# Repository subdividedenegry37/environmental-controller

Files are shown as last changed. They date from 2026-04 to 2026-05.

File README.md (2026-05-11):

# Environmental Controller

Dual-relay humidity and vapor pressure deficit (VPD) controller built around a custom ESP32/RP2040 PCB.
End-to-end project: firmware, schematic, 2-layer PCB layout, and 3D-printed enclosure, all designed and built from scratch.

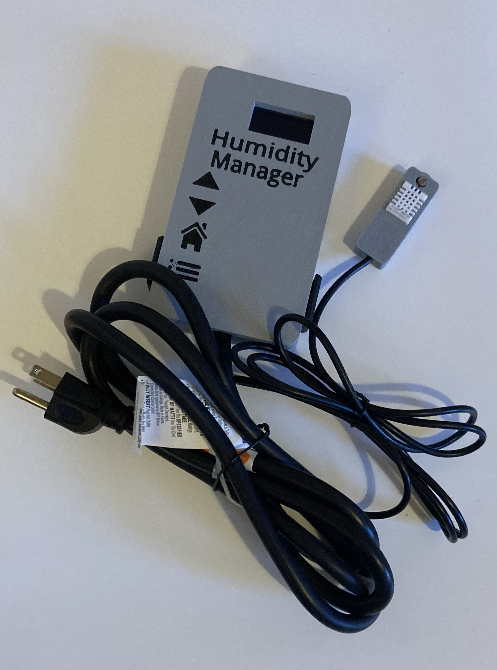
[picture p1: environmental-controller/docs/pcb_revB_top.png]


---

## What it does

Enviirmental controller that targets VPD rather than relitive humidity. Monitors temperature, humidity amd computes VPD. Controller switches between AC relays driving a humidifier or a dehumidifier to hold a target VPD during the day. Additional Day/night setting controlled by ambient light sensor. Four pushbuttons and a 128×64 OLED display provide a UI for setting targets, sensor offsets, and display preferences. All user settings are persisted to flash and restored on power-up.

Applications for a VPD/humidity controller of this class include greenhouse and horticulture environments, cleanroom and storage humidity control, museum and archive climate control, and any enclosed space where temperature-compensated humidity targeting is preferable to raw RH control.

---

## Hardware

**Microcontroller:** RP2040 soldered directly to the board with minimal design. Onboard USB-to-serial IC handles programming and debug. BOOT and RESET buttons are broken out to the board edge.

**Sensors:**
- DHT22 (AM2302) digital temperature and humidity sensor
- Analog photoresistor for ambient light / day–night detection

**Output stage:**
- Two 5V mechanical relays switching 120 VAC mains loads
- Flyback diodes on each relay coil for back-EMF protection
- Slot cutout between the low-voltage logic section and the AC main section for creepage clearance isolation

**User interface:**
- SSH1106 128×64 I2C OLED display
- Four momentary pushbuttons (up, down, back, next/settings)

**Power and I/O:**
- 120 VAC mains input via screw terminals (L, N)
- Two switched 120 VAC output terminals (O1, O2) for humidifier and dehumidifier loads
- 3.3 V logic rail for ESP32 and sensors
- Sensor pin header breakout for DHT22, light sensor, GND, and 3V3

---

## Firmware

Initial Arduino-framework C++ (`RewriteV4_5.ino`), targeting the ESP32 via the Arduino core. Key design decisions:

**Non-blocking main loop.** No `delay()` calls in the main execution path. Each subsystem — sensor reads, display refresh, EEPROM save check, light sensor averaging — runs on its own cadence using `millis()` deltas. This keeps the UI responsive and the control loop prompt regardless of what any one subsystem is doing.

**Hysteretic relay control with dead time compensation.** The DHT22 responds in seconds, but room air takes minutes to actually equilibrate after a humidifier or dehumidifier kicks on. Without a tolerance band around the setpoint, the fast sensor response versus slow physical response produces continuous oscillation and cycles the relays constantly. The control logic tracks which device was most recently active and uses a tolerance band to define a dead zone around the target — the relay does not re-engage until the measurement crosses the opposite side of the band. This both prevents oscillation and extends mechanical relay life.

**Sensor smoothing via moving averages.** DHT22 outputs are noisy by nature; the analog photoresistor is noisier still. Each sensor feeds a 10-sample ring buffer, and control decisions are made against the average rather than the instantaneous reading.

**EEPROM wear protection.** The save routine fires on a 30-second timer but only performs EEPROM writes if any stored value has actually changed since the last save. This bounds EEPROM cycling to actual user interaction and prevents flash wear from the periodic poll.

**Independent day and night control modes.** Day mode targets VPD (a combined function of temperature and humidity); night mode targets relative humidity directly. Mode switches automatically from the light sensor reading with a configurable cutoff threshold.

**State-machine UI.** A `SettingsScreenState` byte drives a six-screen menu (VPD target, humidity offset, temperature offset, leaf offset, night mode enable, night humidity target). Button mapping is context-sensitive to the active screen.

---

## PCB

Full 2-layer PCB designed in EasyEDA. Complete Gerber sets for both revisions are included in `pcb/`, ready to send to any fab house.

**Revision A — initial working board:**

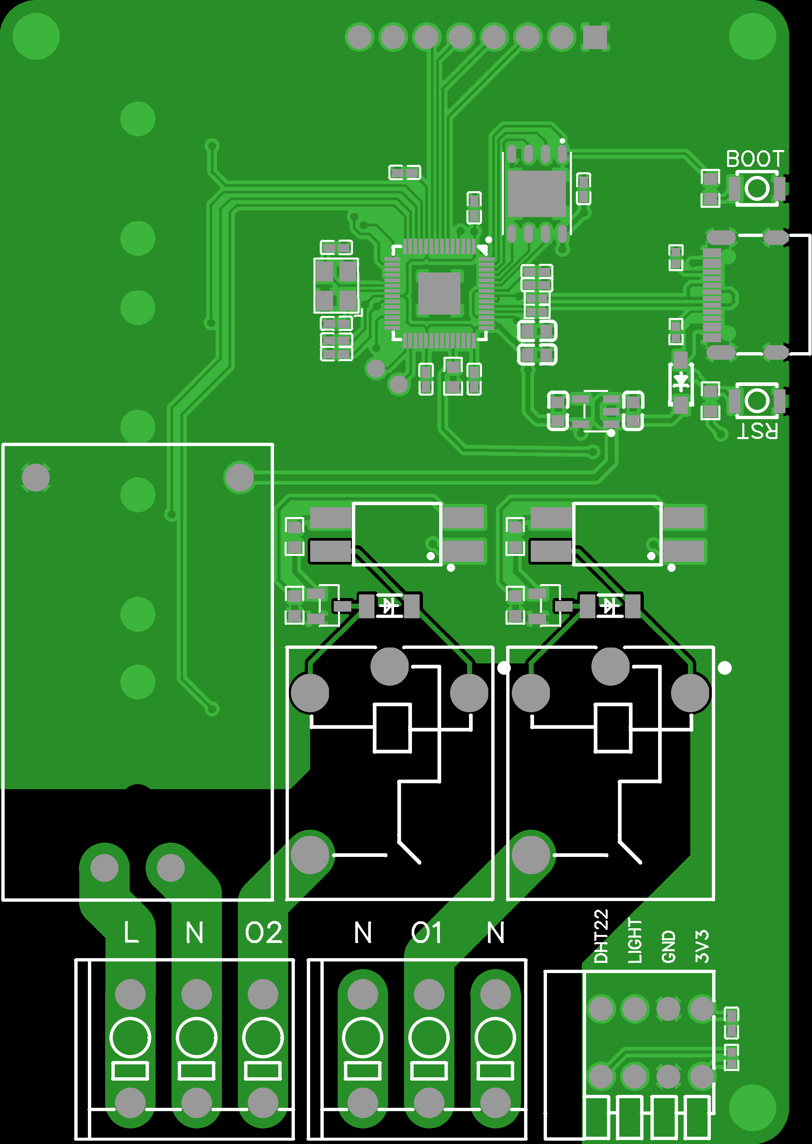
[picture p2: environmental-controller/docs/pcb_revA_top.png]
PCB revision A, top view


3rd ideration of board, self driven, added spring clamp, button header, and display header to aid in assembly. Added additional saftey features as well to manage AC/DC seperation.

**Revision B — refined layout:**

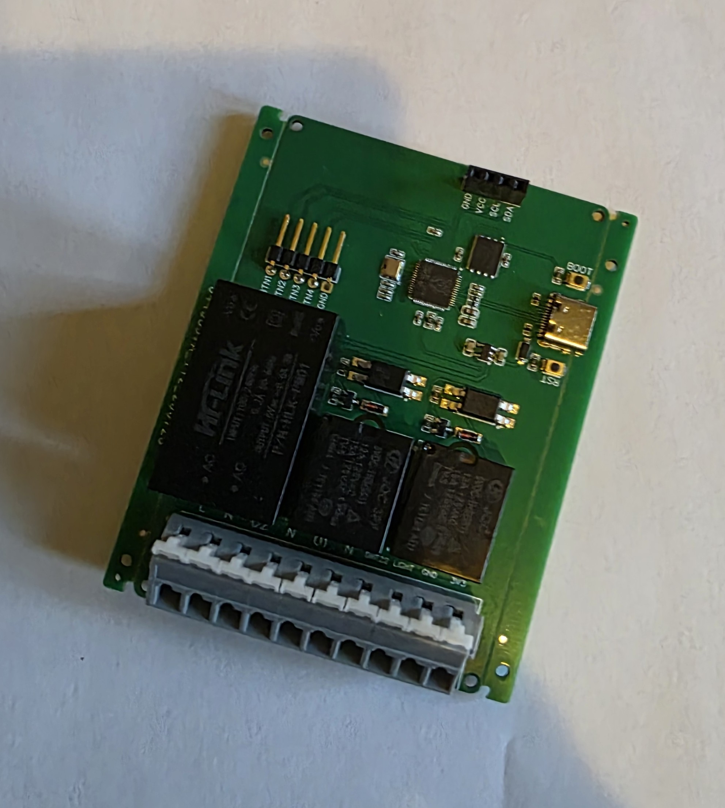
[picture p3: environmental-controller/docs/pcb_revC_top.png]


Unified terminal strip along the bottom edge for all power and sensor connections, dedicated labeled headers for the four front-panel buttons (BTN1–BTN4), and an explicit I2C header at the top (GND/VCC/SCL/SDA) for the OLED. 

Both revisions keep a slot cutout between the mains and logic sections for creepage clearance — standard safety practice for any PCB that switches AC line voltage from the same board as its low-voltage logic.

**Design history.** Initial PCB layout was attempted through two contracted specialists via freelancing platforms; neither delivered a working board. Rather than continue contracting, the layout was self-taught and done in-house — which turned out to be both faster and better matched to the actual hardware constraints.

---

## Enclosure

3D-printable enclosure designed in Fusion 360, printed on a Bambu Lab multi-color FDM printer to allow the button labels to be printed directly into the top face of the lid rather than applied as stickers or silkscreen. Buttons themselves are nexted into the print as well.

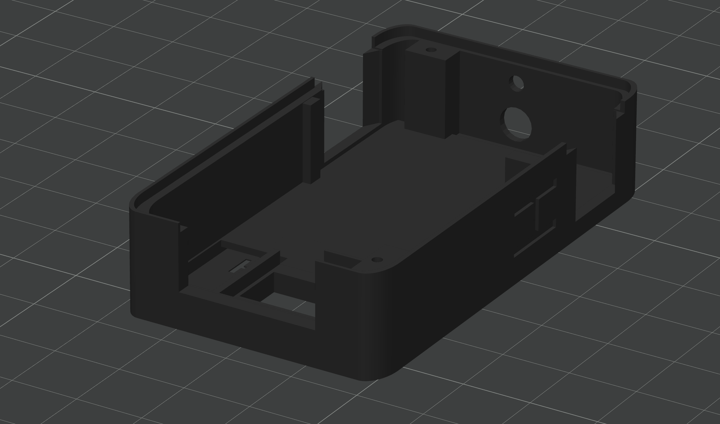
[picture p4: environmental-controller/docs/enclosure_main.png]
Main enclosure


The main box includes a nested button pocket with a thin top layer which gives a cleaner finished look and better tactile feel. Labels are printed directly into the box.

The DHT22 and photoresistor are housed in a small separate enclosure connected to the main unit via a short cable, so the sensor can be positioned at the measurement location independently of the controller.

Both AC outlets clip into place and screen sits directly in the board breakout making for simple assemply.

STL files in `enclosure/`.

---

## Repository layout

```
environmental-controller/
├── firmware/
│   └── RewriteV4_5.ino          Arduino-framework ESP32 firmware
├── pcb/
│   ├── rev_a/                   Gerbers, drill files for first board revision
│   └── rev_b/                   Gerbers, drill files for refined revision
├── enclosure/
│   ├── Box.stl                  Main enclosure body
│   ├── newTopcurveaa.stl        Top cover with button pockets
│   ├── Sensort.stl              Remote sensor housing
│   └── box6.stl                 Alt enclosure revision
├── docs/
│   └── (rendered images used in this README)
└── README.md
```

---

## Status and honest notes

This was an early self-taught embedded-systems project (2019–2022). It was my first serious firmware, first custom PCB, and first real enclosure design. The firmware is kept in its original form rather than refactored to modern practice: there are a lot of global variables, three separate copies of the moving-average logic (one for VPD, one for humidity, one for light), and variable naming is not consistent across the file. The underlying architecture — non-blocking scheduling, hysteretic control with dead-zone compensation, EEPROM wear protection, sensor smoothing, a proper menu state machine — is sound. The surface-level code style reflects someone learning C++ while building the thing.

If I were rebuilding this today, I'd encapsulate the per-sensor state into structs, collapse the three ring-buffer implementations into one reusable class, and move constants and pin assignments into a separate header. None of those changes would alter what the device does; they'd just make the project easier to maintain. For the purposes of keeping an honest record of what I built while teaching myself, the original file stays.

---

## License

MIT

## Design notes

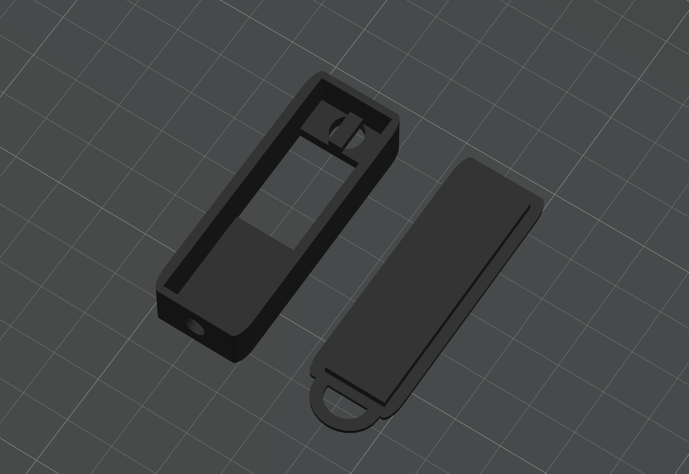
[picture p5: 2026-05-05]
environmental-controller/docs/sensor_housing.png

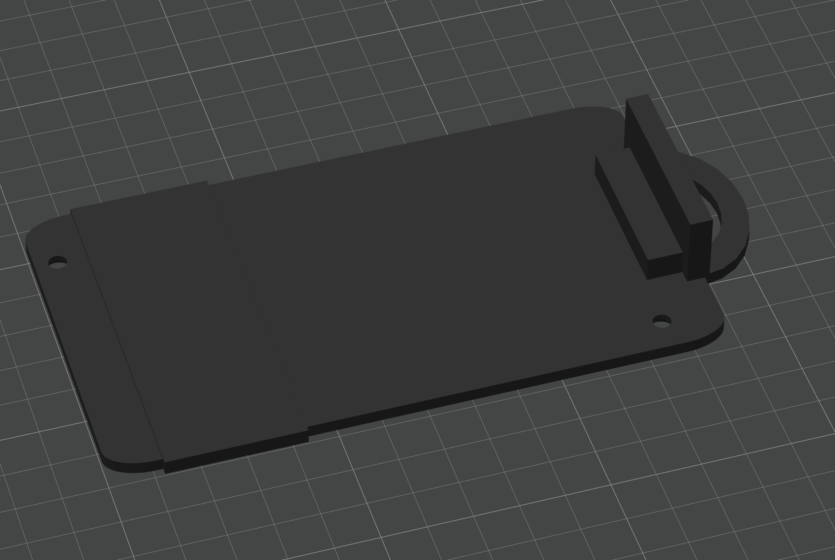
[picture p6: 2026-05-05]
environmental-controller/docs/enclosure_top_cover.png

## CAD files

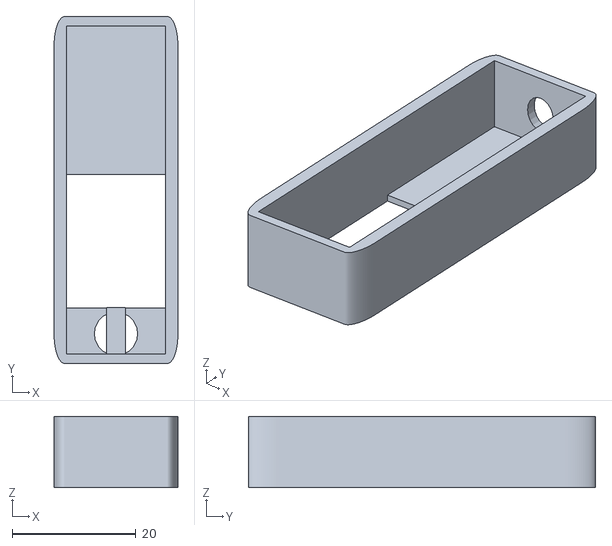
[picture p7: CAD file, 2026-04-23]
environmental-controller/enclosure/box6.stl
20.0 x 56.0 x 11.5

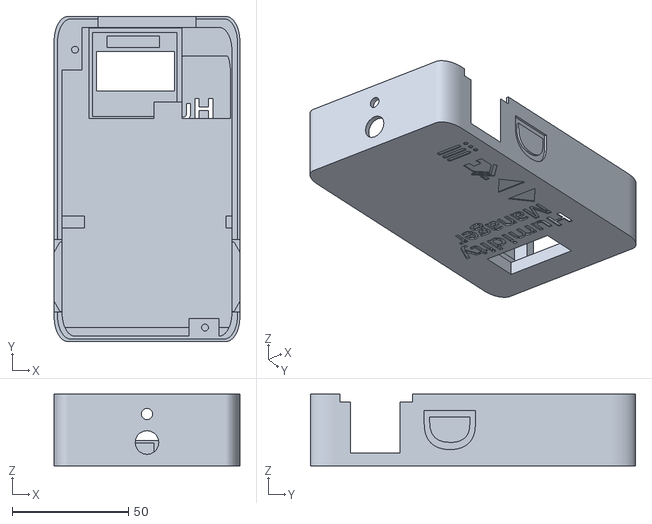
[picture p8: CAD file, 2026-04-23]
environmental-controller/enclosure/Box.stl
80.0 x 140.0 x 31.0

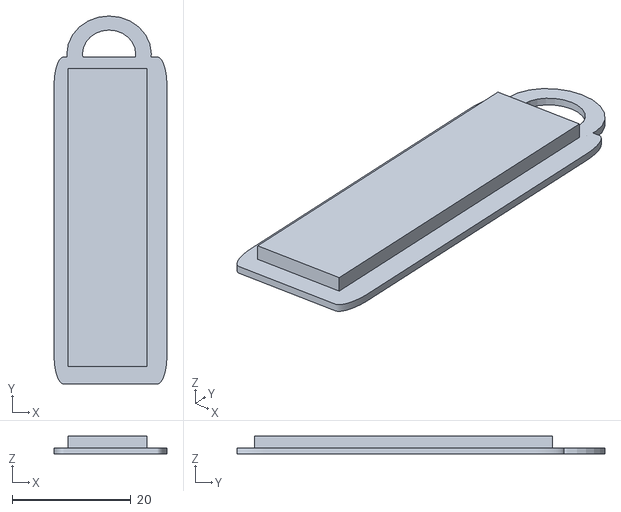
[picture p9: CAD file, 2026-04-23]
environmental-controller/enclosure/Sensort.stl
19.0 x 62.0 x 3.00

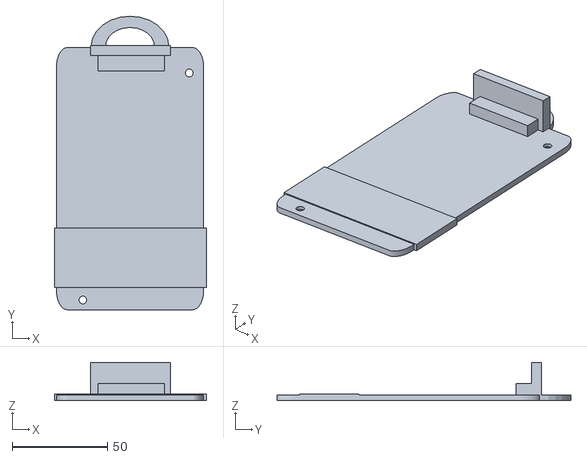
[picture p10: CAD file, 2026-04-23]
environmental-controller/enclosure/newTopcurveaa.stl
80.0 x 154.5 x 20.0

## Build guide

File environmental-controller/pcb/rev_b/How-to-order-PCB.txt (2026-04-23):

How to Order PCB

Please refer to:
https://docs.easyeda.com/en/PCB/Order-PCB

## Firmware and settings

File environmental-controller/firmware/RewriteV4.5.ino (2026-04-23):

/*
 * Environmental Controller
 *
 * Dual-relay humidity / vapor pressure deficit (VPD) controller for an
 * enclosed environment. Reads temperature and relative humidity from a
 * DHT22, reads ambient light from an analog photoresistor, and drives
 * two AC relays (humidifier and dehumidifier) through a hysteretic
 * control loop with independent day and night modes.
 *
 * Hardware:
 *   - Arduino Uno / Nano (ATmega328P)
 *   - DHT22 temperature and humidity sensor
 *   - SSH1106 128x64 I2C OLED display
 *   - Analog photoresistor / LDR for day-night detection
 *   - Two mechanical relays driving 120VAC loads
 *   - Four momentary pushbuttons for menu control
 *   - Settings persisted to on-board EEPROM
 *
 * Control strategy:
 *   - 10-sample moving averages on temperature, humidity, and light
 *     readings to reject DHT22 noise and smooth analog variation
 *   - Hysteresis bands around target values to accommodate the dead
 *     time between relay switching and room-air equilibration. Without
 *     this, fast sensor response versus slow physical response produces
 *     continuous oscillation around the setpoint.
 *   - Day mode targets VPD (function of temperature and humidity);
 *     night mode targets relative humidity directly
 *   - EEPROM writes gated on change detection to prevent flash wear
 *   - Non-blocking main loop: sensors, display, EEPROM, and light
 *     sensor each run on independent timers using millis() deltas
 *
 * Status:
 *   Early self-taught embedded project (2020-2022). Kept in its
 *   original working form; heavy use of globals and repeated
 *   moving-average implementations reflect that origin.
 */

#include <Wire.h>
#include <EEPROM.h>
#include <DHT.h>

// Screen Set Up
#include <GyverOLED.h>
GyverOLED<SSH1106_128x64> oled;

// Sensor Set Up
#define DHTPIN 2
#define DHTTYPE DHT22
DHT dht(DHTPIN, DHTTYPE);

// Humidifier and Dehumidifier Settings
bool LastOnDehumidifier = false;
bool LastOnHumidifier = false;

// VPD
float StoredVPDMovingAverage[10] = {0, 0, 0, 0, 0, 0, 0, 0, 0, 0};
byte LastVPDArrayPos = 0;
float AveragedVPD = 0;
float CurrentVPD = 0;

// Humidity Sensor
float AveragedHumidity = 0;
byte LastHumArrayPos = 0;
float StoredHumidityMovingAverage[10] = {0, 0, 0, 0, 0, 0, 0, 0, 0, 0};

// Light Sensor
byte LastLightArrayPos = 0;
float LightTotalValues = 0;
int LightArraySize = 10;
float AvLight = 0;
float LightAnalog_Reading = 0; // light array readings are different, narrowning problem
float LightMovingAverage[10] = {0, 0, 0, 0, 0, 0, 0, 0, 0, 0};

// Settings Vars
float TargetVPD = 1;
const float VPDTolerance = .1;

float NightModeTargetHumidity = 60;
const float NightModeHumidityTolerance = 2;

int LeafOffset = 0;
int HumidityOffset = 0;
float TempOffset = 0;

bool DisplayF = true;
byte SettingsScreenState = 0;
bool SleepMode = false;
bool NightMode = false;
bool NightModeEnabled = false;
byte RelaySetting = 0;

int LightSensorCutoff = 950;


// Relay Pins
const byte HumidifierPin = 10;
const byte DehumidifierPin = 11;





// Timer Vars
unsigned long debounceDelay = 100;    //debounce delay
const int UpdateDelayEEPROM = 30000; // How long between EEPROM checks
const int UpdateDelaySensor = 2000; // How long between Temp & Humidity Sensor checks
const int UpdateDelayScreen = 2000; // How long between Screen Refreshes
const int UpdateDelayLightSensor = 1000; // How long between Light Sensor Refreshes
unsigned long SleepDelay = 300000; // How long until screen goes to Sleep

unsigned long lastDebounceTime = 0;  // Time since the button pin was toggled
unsigned long StartTimeEEPROM = 0; // Start Time for EEPROM cycle
unsigned long StartTimeSensor = 0; // Start Time for Sensor cycle
unsigned long StartTimeScreen = 0; // Start Time for Screen cycle
unsigned long StartTimeSleep = 0; // Start Time for Sleep cycle
unsigned long StartTimeLightSensor = 0; // Start Time for Light Sensor cycle

unsigned long PresentTime = 0; // variable for storing the present time


// Menu Vars
const byte Button1Pin = 6;
const byte Button2Pin = 7;
const byte Button3Pin = 8;
const byte Button4Pin = 9;
int Button1Status = HIGH;
int Button2Status = HIGH;
int Button3Status = HIGH;
int Button4Status = HIGH;
int Button1LastState = HIGH;
int Button2LastState = HIGH;
int Button3LastState = HIGH;
int Button4LastState = HIGH;
bool ButtonReady = false;


// EEPROM
bool FirstTimeRun = true;
const byte StoredFirstTimeAddress = 6;
const byte StoredVPDSettingAddress = 11;
const byte StoredLeafOffsetAddress = 16;
const byte StoredTempOffsetAddress = 21;
const byte StoredHumidityOffsetAddress = 26;
const byte StoredTempScaleSettingAddress = 31;
const byte StoredNightModeEnabledAddress = 37;
const byte StoredNightModeHumidityAddress = 41;




void setup() {
  bool FirstTimeSetting;
  Serial.begin(9600);
  EEPROM.begin(512);
  delay(1000);

  // Buttons
  pinMode(Button1Pin, INPUT_PULLUP); //Button 1 Pin
  pinMode(Button2Pin, INPUT_PULLUP); //Button 2 Pin
  pinMode(Button3Pin, INPUT_PULLUP); //Button 3 Pin
  pinMode(Button4Pin, INPUT_PULLUP); //Button 4 Pin

  // Screen Pins
  pinMode (4, SDA);
  pinMode (5, SCL);

  // Humidity Sensor
  dht.begin();
  pinMode(13, OUTPUT);
  digitalWrite(13, LOW);
  pinMode(12, OUTPUT);
  digitalWrite(12, HIGH);
  pinMode(3, OUTPUT);
  digitalWrite(3, HIGH);
  pinMode(21, OUTPUT);
  digitalWrite(21, HIGH);

  // Relay Pins
  pinMode(HumidifierPin, OUTPUT);
  pinMode(DehumidifierPin, OUTPUT);


  // Light Sensor
pinMode(A1, INPUT_PULLDOWN);



  // Check for Stored Settings
  EEPROM.get(StoredFirstTimeAddress, FirstTimeSetting);
  if (FirstTimeSetting != false) {
    FirstTimeRun = false;
    EEPROM.put(StoredFirstTimeAddress, FirstTimeRun);
    EEPROM.commit();
  }
  // Update settings if not first time run

  else {
    EEPROM.get(StoredVPDSettingAddress, TargetVPD);
    EEPROM.get(StoredLeafOffsetAddress, LeafOffset);
    EEPROM.get(StoredTempOffsetAddress, TempOffset);
    EEPROM.get(StoredHumidityOffsetAddress, HumidityOffset);
    EEPROM.get(StoredTempScaleSettingAddress, DisplayF);
    EEPROM.get(StoredNightModeEnabledAddress, NightModeEnabled);
    EEPROM.get(StoredNightModeHumidityAddress, NightModeTargetHumidity);
  }

  //Set up Display
  oled.init();

  delay(1000);
  UpdateRelaySettings();
  DisplayHomeScreen();
}




void loop() {
  const float VPDSettingMax = 1.6;
  const float VPDSettingMin = .4;

  const int LeafSettingMax = 0;
  const int LeafSettingMin = -5;
  const int HumiditySettingMax = 50;
  const int HumiditySettingMin = -50;
  const int TempSettingMax = 50;
  const int TempSettingMin = -50;
  const float NightModeTargetHumidityMax = 100;
  const float NightModeTargetHumidityMin = 1;
  const int NumOfSettings = 6;


  PresentTime = millis(); // Updating the value of PresentTime

  // Read Buttons
  int Button1Read = digitalRead(Button1Pin);
  int Button2Read = digitalRead(Button2Pin);
  int Button3Read = digitalRead(Button3Pin);
  int Button4Read = digitalRead(Button4Pin);


  /* ==============Check if any buttons are pressed============== */
  if (Button1Read != Button1LastState || Button2Read != Button2LastState || Button3Read != Button3LastState || Button4Read != Button4LastState) {
    lastDebounceTime = millis();
  }


  // if debounce timer has elapsed since button press and values stayed the same
  if ((millis() - lastDebounceTime) > debounceDelay) {
    if (Button1Read != Button1Status) {
      Button1Status = Button1Read;
    }
    else if (Button2Read != Button2Status) {
      Button2Status = Button2Read;
    }
    else if (Button3Read != Button3Status) {
      Button3Status = Button3Read;
    }
    else if (Button4Read != Button4Status) {
      Button4Status = Button4Read;
    }



    if (Button1Status == LOW || Button2Status == LOW || Button3Status == LOW || Button4Status == LOW) {
      StartTimeSleep = PresentTime; // Reset Sleep timer's passed time value
      if (SleepMode == true) { // If in sleep, wake up and do not execute button press
        SleepMode = false;
        DisplayHomeScreen();
      }

      else if (SleepMode == false) {
        // If not in sleep mode, execute button press

        // If on Home Screen
        if (SettingsScreenState == 0) {

          if (Button1Status == LOW) {
            if (TargetVPD < VPDSettingMax) {
              TargetVPD = TargetVPD + .1;
            }

          }
          if (Button2Status == LOW) {

            if (TargetVPD > VPDSettingMin) {
              TargetVPD = TargetVPD - .1;
            }
          }
          if (Button3Status == LOW) {
            SleepMode = true;
            oled.clear();
            oled.update();
          }
          if (Button4Status == LOW) {
            SettingsScreenState = 1;

          }
        }

        // If on Setting Screen 1 - Humidity Offset
        else if (SettingsScreenState == 1) {
          if (Button1Status == LOW) {
            // Increase Setting if below Max

            if (HumidityOffset < HumiditySettingMax) {
              HumidityOffset = HumidityOffset + 1;
            }
          }
          if (Button2Status == LOW) {
            // Decrease Setting if above Min

            if (HumidityOffset > HumiditySettingMin) {
              HumidityOffset = HumidityOffset - 1;
            }

          }
          if (Button3Status == LOW) {
            // Go to Home Screen
            SettingsScreenState = 0;
          }

          if (Button4Status == LOW) { // Next Setting

            if (SettingsScreenState < NumOfSettings) {
              SettingsScreenState++;

            }
            else {
              SettingsScreenState = 1;
            }

          }

        }

        // If on Setting Screen 2 - Leaf Offset
        else if (SettingsScreenState == 2) {
          if (Button1Status == LOW) {
            // Increase Setting if below Max
            if (LeafOffset < LeafSettingMax) {
              LeafOffset = LeafOffset + 1;
            }

          }
          if (Button2Status == LOW) { // Decrease Setting if above Min

            if (LeafOffset > LeafSettingMin) {
              LeafOffset = LeafOffset - 1;
            }
          }
          if (Button3Status == LOW) { // Go to Home Screen
            SettingsScreenState = 0;
          }

          if (Button4Status == LOW) { // Next Setting

            if (SettingsScreenState < NumOfSettings) {
              SettingsScreenState++;

            }
            else {
              SettingsScreenState = 1;
            }

          }
        }

        // If on Setting Screen 3 - Temperature Offset
        else if (SettingsScreenState == 3) {
          if (Button1Status == LOW) {
            // Increase Setting if below Max
            if (TempOffset < TempSettingMax) {
              TempOffset = TempOffset + 1;
            }

          }
          if (Button2Status == LOW) {
            // Decrease Setting if above Min

            if (TempOffset > TempSettingMin) {
              TempOffset = TempOffset - 1;
            }
          }
          if (Button3Status == LOW) {
            // Go to Home Screen
            SettingsScreenState = 0;
          }

          if (Button4Status == LOW) { // Next Setting

            if (SettingsScreenState < NumOfSettings) {
              SettingsScreenState++;

            }
            else {
              SettingsScreenState = 1;
            }

          }
        }

        // If on Setting Screen 4 - Toggle Fahrenheit or Celsius
        else if (SettingsScreenState == 4) {
          if (Button1Status == LOW || Button2Status == LOW) {
            // Toggle C or F
            if (DisplayF == true) {
              DisplayF = false;
            }
            else {
              DisplayF = true;
            }
          }

          if (Button3Status == LOW) {
            // Go to Home Screen
            SettingsScreenState = 0;
          }

          if (Button4Status == LOW) {
            // Next Setting

            if (SettingsScreenState < NumOfSettings) {
              SettingsScreenState++;

            }
            else {
              SettingsScreenState = 1;
            }

          }
        }

        // If on Setting Screen 5
        else if (SettingsScreenState == 5) {
          if (Button1Status == LOW || Button2Status == LOW) {
            // Toggle NightMode
            if (NightModeEnabled == true) {
              NightModeEnabled = false;
            }
            else {
              NightModeEnabled = true;
            }
          }

          if (Button3Status == LOW) { // Go to Home Screen
            SettingsScreenState = 0;
          }

          if (Button4Status == LOW) { // Next Setting

            if (SettingsScreenState < NumOfSettings) {
              SettingsScreenState++;

            }
            else {
              SettingsScreenState = 1;
            }

          }
        }


        // If on Setting Screen 6 - Humidity Setting for NightMode
        else if (SettingsScreenState == 6) {
          // Increase Setting if below Max
          if (Button1Status == LOW) {

            if (NightModeTargetHumidity < NightModeTargetHumidityMax) {
              NightModeTargetHumidity = NightModeTargetHumidity + 1;
            }

          }
          // Decrease Setting if above Min
          if (Button2Status == LOW) {

            if (NightModeTargetHumidity > NightModeTargetHumidityMin) {
              NightModeTargetHumidity = NightModeTargetHumidity - 1;
            }
          }
          if (Button3Status == LOW) { // Go to Home Screen
            SettingsScreenState = 0;
          }

          if (Button4Status == LOW) { // Next Setting

            if (SettingsScreenState < NumOfSettings) {
              SettingsScreenState++;

            }
            else {
              SettingsScreenState = 1;
            }

          }
        }


        //Displaylatest after any button is pressed
        if (SleepMode == false) {
          if (SettingsScreenState == 0) {
            DisplayHomeScreen();
          }
          else {
            DisplaySettingScreen(SettingsScreenState);
          }
        }
      }

    }
    else {
      if ((PresentTime - StartTimeSleep >= SleepDelay) && (SleepMode == false)) { // If time passed since last button press is greater or equal to SleepDelay AND Sleep Mode is off, put screen to sleep
        SleepMode = true;
        oled.clear();
        oled.update();
      }
    }
    lastDebounceTime = millis();
  }

  Button1LastState = Button1Read;
  Button2LastState = Button2Read;
  Button3LastState = Button3Read;
  Button4LastState = Button4Read;

  /* ==============Temp & Humidity Sensor============== */
  if ((PresentTime - StartTimeSensor) >= UpdateDelaySensor) { // Check if time passed is equal to or more than elapsed time since this cycle started

    UpdateRelaySettings();

    StartTimeSensor = PresentTime; // updating the passed time value
  }

  /* ==============Screen============== */
  if (((PresentTime - StartTimeScreen) >= UpdateDelayScreen) && (SleepMode == false)) { // Check if time passed is equal to or more than the delay time since this cycle started and Sleep Mode is off

    // If on Home screen, Displaycurrent stats
    if (SettingsScreenState == 0) {
      DisplayHomeScreen();
    }
    // If on Setting Screen, Displaycurrent Setting Screen
    //  else {
    //    DisplaySettingScreen(SettingsScreenState);
    //  }

    StartTimeScreen = PresentTime; // updating the passed time value
  }

  /* ==============EEPROM============== */


  if ((PresentTime - StartTimeEEPROM) >= UpdateDelayEEPROM) { // Check if time passed is equal to or more than elapsed time since this cycle started
    SaveToFlash();
    StartTimeEEPROM = PresentTime; // updating the passed time value
  }


  /* ==============Light Sensor============== */
  if ((PresentTime - StartTimeLightSensor) >= UpdateDelayLightSensor) { // Check if time passed is equal to or more than elapsed time since this cycle started
    
    LightTotalValues = 0;
    LightArraySize = 10;
    LightAnalog_Reading = analogRead(A1); // getting value for a print command
    LightMovingAverage[LastLightArrayPos] = LightAnalog_Reading;

    if (LastLightArrayPos < 9) {
      LastLightArrayPos++;
    }
    else
    {
      LastLightArrayPos = 0;
    }

    // Find average of all values in the array
    for (int x = 0; x < 10; x++) {
      if (LightMovingAverage[x] != 0) {
        LightTotalValues = LightTotalValues + LightMovingAverage[x];
      }
      else {
        LightArraySize--;
      }
    }
    AvLight = LightTotalValues / LightArraySize;



    if (NightModeEnabled == true) {
      if (AvLight <= LightSensorCutoff) {
        NightMode = true;
      }
      if (AvLight > LightSensorCutoff) {
        NightMode = false;
      }
    }
    StartTimeLightSensor = PresentTime; // updating the passed time value
  }

}
void SaveToFlash() {

  bool HasValueChanged = false;
  float LastSaveTargetVPD;
  int LastSaveLeafOffset;
  int LastSaveHumidityOffset;
  float LastSaveTempOffset;
  bool LastSaveDisplayF;
  bool LastSaveNightModeEnabled;
  float LastSaveNightModeTargetHumidity;


  EEPROM.get(StoredVPDSettingAddress, LastSaveTargetVPD);
  EEPROM.get(StoredLeafOffsetAddress, LastSaveLeafOffset);
  EEPROM.get(StoredTempOffsetAddress, LastSaveTempOffset);
  EEPROM.get(StoredHumidityOffsetAddress, LastSaveHumidityOffset);
  EEPROM.get(StoredTempScaleSettingAddress, LastSaveDisplayF);
  EEPROM.get(StoredNightModeEnabledAddress, LastSaveNightModeEnabled);
  EEPROM.get(StoredNightModeHumidityAddress, LastSaveNightModeTargetHumidity);

  if (LastSaveTargetVPD != TargetVPD) {
    HasValueChanged = true;
  }
  if (LastSaveLeafOffset != LeafOffset) {
    HasValueChanged = true;
  }
  if (LastSaveTempOffset != TempOffset) {
    HasValueChanged = true;
  }
  if (LastSaveHumidityOffset != HumidityOffset) {
    HasValueChanged = true;
  }
  if (LastSaveDisplayF != DisplayF) {
    HasValueChanged = true;
  }
  if (LastSaveNightModeEnabled != NightModeEnabled) {
    HasValueChanged = true;
  }
  if (LastSaveNightModeTargetHumidity != NightModeTargetHumidity) {
    HasValueChanged = true;
  }

  if (HasValueChanged == true) {
    EEPROM.put(StoredVPDSettingAddress, TargetVPD);
    EEPROM.put(StoredLeafOffsetAddress, LeafOffset);
    EEPROM.put(StoredTempOffsetAddress, TempOffset);
    EEPROM.put(StoredHumidityOffsetAddress, HumidityOffset);
    EEPROM.put(StoredTempScaleSettingAddress, DisplayF);
    EEPROM.put(StoredNightModeEnabledAddress, NightModeEnabled);
    EEPROM.put(StoredNightModeHumidityAddress, NightModeTargetHumidity);
    EEPROM.commit();

  }
}



// Find current VPD
float FindVPD() {

  // Check current humidity
  float CurrentHumidity = dht.readHumidity();
  // Read temperature as Celsius
  float CurrentTemp = dht.readTemperature();

  // Adjusted values based on Settings
  float AdjustedHumidity = CurrentHumidity + HumidityOffset;
  float AdjustedTemp = CurrentTemp + ((TempOffset * 5) / 9);



  //leaf offset is using the Saturation pressure of the leaf compared to the room
  float leaf = 0.611 * exp((17.502 * (AdjustedTemp + LeafOffset)) / ((AdjustedTemp + LeafOffset) + 240.97));
  float e_sat = 0.611 * exp((17.502 * AdjustedTemp) / (AdjustedTemp + 240.97));
  float e_act = e_sat * AdjustedHumidity / 100;
  float VPD = leaf - e_act;

  return (VPD);
}


// Return moving average for VPD
float VPDMovingAverage() {

  float AvVPD;
  float TotalValues = 0;
  int ArraySize = 10;

  // Add newest value to array
  StoredVPDMovingAverage[LastVPDArrayPos] = FindVPD();

  if (LastVPDArrayPos < 9) {
    LastVPDArrayPos++;
  }
  else {
    LastVPDArrayPos = 0;
  }



  // Find average of all values in the array
  for (int x = 0; x < 10; x++) {
    if (StoredVPDMovingAverage[x] != 0) {
      TotalValues = TotalValues + StoredVPDMovingAverage[x];
    }
    else {
      ArraySize--;
    }
  }
  AvVPD = TotalValues / ArraySize;

  /*
    Serial.println("xxxxxxxxxxx");
    Serial.print("Total Value: ");
    Serial.println(TotalValues);
    Serial.print("ArraySize: ");
    Serial.println(ArraySize);
    Serial.print("AvVPD: ");
    Serial.println(AvVPD);
    Serial.println("xxxxxxxxxxx");
  */
  return (AvVPD);
}

// Return moving average for Humidity
float HumidityMovingAverage() {

  float AvHumidity;
  float TotalValues = 0;
  int ArraySize = 10;


  // Add newest value to array
  StoredHumidityMovingAverage[LastHumArrayPos] = dht.readHumidity();
  if (LastHumArrayPos < 9) {
    LastHumArrayPos++;
  }
  else {
    LastHumArrayPos = 0;
    
  }


  // Find average of all values in the array
  for (int x = 0; x < 10; x++) {
    if (StoredHumidityMovingAverage[x] != 0) {
      TotalValues = TotalValues + StoredHumidityMovingAverage[x];
    }
    else {
      ArraySize--;
    }
  }
  AvHumidity = TotalValues / ArraySize;
  return (AvHumidity);
}


void DisplayHomeScreen() {
  oled.clear();
  oled.home();
  oled.setScale(1);

  float AdjustedTemp = 0;
  // DisplayTemp in F or C
  if (DisplayF == false) {
    AdjustedTemp = dht.readTemperature() + ((TempOffset * 5) / 9);
    oled.print(F("Temp: "));
    oled.print(AdjustedTemp);
    oled.println(F(" C"));

  }
  else {
    AdjustedTemp = dht.readTemperature() + ((TempOffset * 5) / 9);
    AdjustedTemp = (AdjustedTemp * 1.8) + 32; // convert to F
    oled.print(F("Temp: "));
    oled.print(AdjustedTemp);
    oled.println(F(" F"));
  }

  // DisplayHumidity
  float CurrentHumidity = dht.readHumidity();
  oled.print(F("Humidity: "));
  oled.println(CurrentHumidity + HumidityOffset);


  // DisplayRoom VPD
  oled.print(F("Current VPD: "));
  oled.println(VPDMovingAverage());

  // DisplayTarget VPD
  oled.print(F("Target VPD: "));
  oled.println(TargetVPD);

  //TEMP - Avg Light
  oled.print(F("Avg Light: "));
  oled.println(AvLight);
  oled.println(LightAnalog_Reading);
  oled.update();
}
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
